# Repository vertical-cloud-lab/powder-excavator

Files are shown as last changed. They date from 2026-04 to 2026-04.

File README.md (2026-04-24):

# powder-excavator

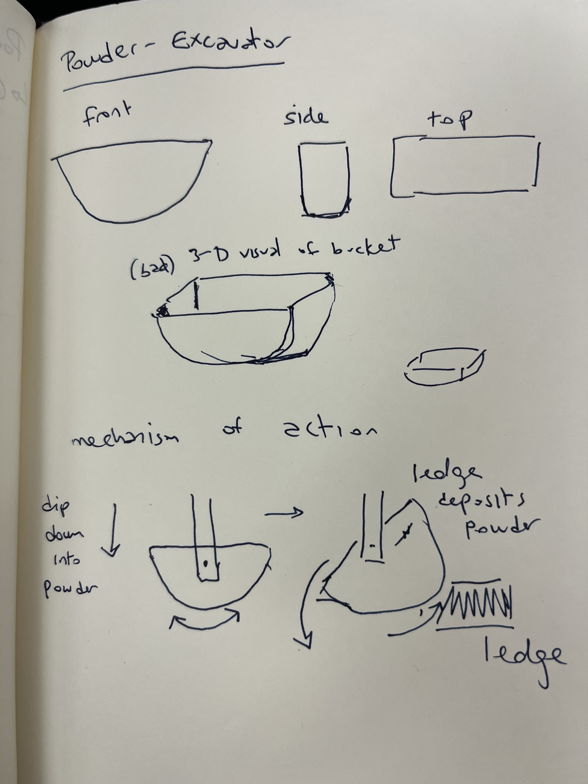
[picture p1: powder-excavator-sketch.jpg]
Design sketch


Alternative dosing-style brainstorm (issue
[#12](https://github.com/vertical-cloud-lab/powder-excavator/issues/12)):
[`docs/alternative-dosing/brainstorm.md`](docs/alternative-dosing/brainstorm.md).

Preliminary design for the top-ranked alternative-dosing concepts
(tap-driven sieve cup + ERM-augmented variant, with bed-mounted
anvil): [`docs/preliminary-design-sieve-cup.md`](docs/preliminary-design-sieve-cup.md)
— printable parts in [`cad/`](cad/).

Per-concept preliminary CAD for **all eight** alternatives (A–H),
each with its own SCAD source, manifold-checked STL, iso PNG,
half-cutaway PNG, transparent rotating GIF, and PrusaSlicer slice
sanity-check:
[`docs/alternative-dosing/per-concept-designs.md`](docs/alternative-dosing/per-concept-designs.md)
— printable parts in [`cad/alternatives/`](cad/alternatives/).

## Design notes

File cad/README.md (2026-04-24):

# Printing & prototyping the alternative-dosing top-ranked sieve cup

This folder contains the parametric, printable CAD for the **two
top-ranked alternative powder-dosing concepts** from
[`docs/alternative-dosing/brainstorm.md`](../docs/alternative-dosing/brainstorm.md):

- **Concept G — ERM-augmented sieve cup** (rank 1 in the
  Edison-revised ranking).
- **Concept A — tap-driven sieve cup** (rank 2; same printed cup,
  fully passive, gantry-as-actuator).

Both share the **same parametric body** so a single SCAD file emits
either variant by toggling one flag. A separate, small bed-mounted
**anvil** is provided for concept A.

It's everything you need to take the design from "interesting plot
in a PR" to "physical part on a 3018-Pro V2 gantry tonight" — the
same procedure used in PR #2 (cam-ramp scoop) and PR #5 (bimodal
trough), and the toolchain agreed in PR #7 (OpenSCAD source +
PrusaSlicer CLI for FDM, FreeCAD Path / Kiri:Moto for CNC, manual
sweeps + pandas for design-space exploration, no Optuna /
Ax-BoTorch yet).

## Files

| File | What it is |
| ---- | --- |
| [`sieve_cup.scad`](sieve_cup.scad) | Parametric source, OpenSCAD 2021.01+. Two-in-one: `-D 'erm_motor_pocket=false'` renders concept A, `-D 'erm_motor_pocket=true'` renders concept G. Every dimension is exposed as a top-of-file variable. |
| [`tap_anvil.scad`](tap_anvil.scad) | Parametric source for the bed-mounted anvil that concept A pecks against. Bolts to the 3018-Pro V2 T-slot bed on a 30 × 30 mm M3 hole pattern; central bore receives the dispensed powder into a 15 mm vial. |
| [`sieve-cup.stl`](sieve-cup.stl) | Concept-A (passive) ready-to-slice mesh. Manifold (CGAL `Simple: yes`), 1 874 facets, ≈ 32 × 32 × 40 mm. |
| [`sieve-cup-erm.stl`](sieve-cup-erm.stl) | Concept-G ready-to-slice mesh (adds an ERM pocket + CR2032 holder pocket). Manifold, 2 104 facets. |
| [`tap-anvil.stl`](tap-anvil.stl) | Bed-mounted anvil. Manifold, 892 facets, 60 × 50 × 19 mm. |
| `sieve-cup{,-erm}-iso.png` | Isometric preview renders. |
| [`sieve-cup-spin.gif`](sieve-cup-spin.gif) | 360° turntable spin of concept A — generated by [`scripts/render_sieve_cup.py`](../scripts/render_sieve_cup.py). |
| [`sieve-cup-erm-spin.gif`](sieve-cup-erm-spin.gif) | 360° turntable spin of concept G. |
| [`tap-anvil-spin.gif`](tap-anvil-spin.gif) | 360° turntable spin of the anvil. |

| Concept A (passive) | Concept G (with ERM pocket) | Tap anvil |
| --- | --- | --- |
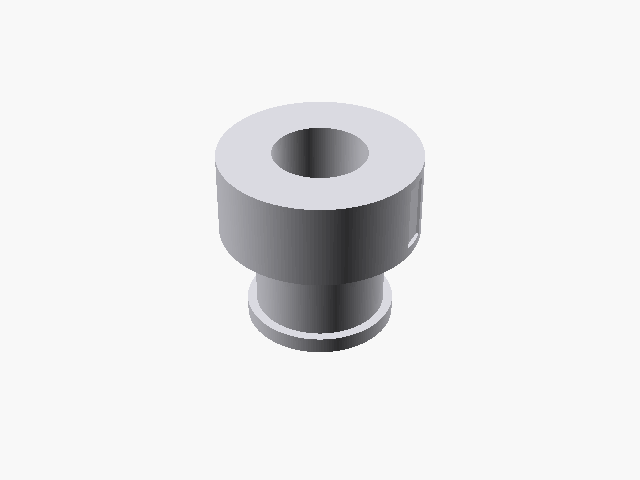
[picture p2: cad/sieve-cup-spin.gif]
sieve cup spin
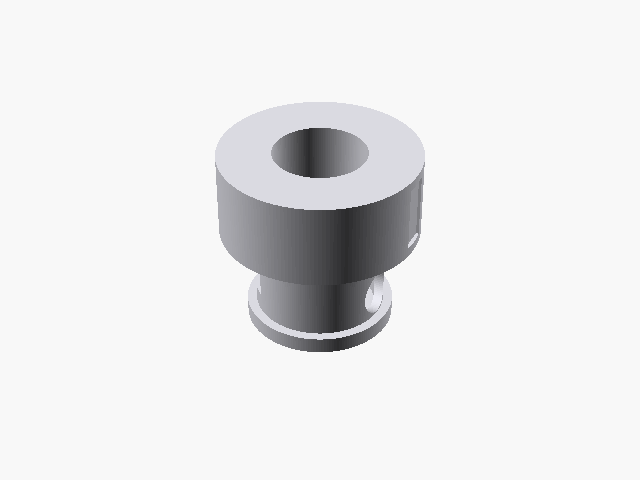
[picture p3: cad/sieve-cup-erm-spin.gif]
sieve cup ERM spin
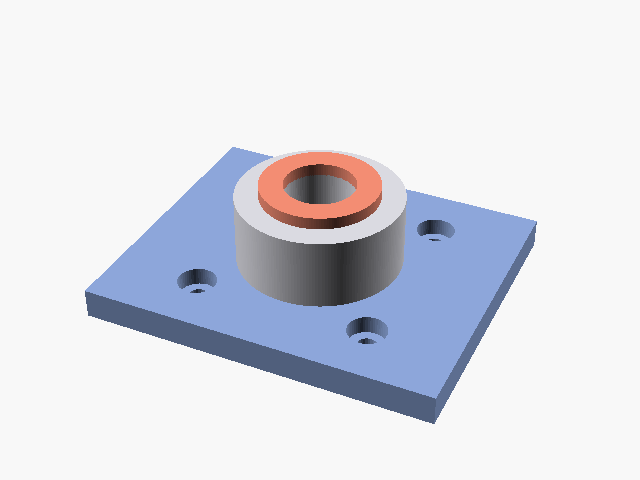
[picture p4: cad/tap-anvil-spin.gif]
tap anvil spin
|  |  |  |

## Re-rendering from source

```bash
sudo apt-get install -y openscad xvfb        # one-time, ~80 MB
pip install pillow

# Concept A (passive, gantry-tap-driven)
openscad -o cad/sieve-cup.stl \
         -D 'erm_motor_pocket=false' cad/sieve_cup.scad
openscad -o cad/sieve-cup-iso.png \
         --imgsize=1100,800 \
         --camera=0,0,18,55,0,25,260 \
         --colorscheme=Tomorrow \
         -D 'erm_motor_pocket=false' cad/sieve_cup.scad

# Concept G (adds ERM motor pocket + coin-cell holder pocket)
openscad -o cad/sieve-cup-erm.stl \
         -D 'erm_motor_pocket=true'  cad/sieve_cup.scad
openscad -o cad/sieve-cup-erm-iso.png \
         --imgsize=1100,800 \
         --camera=0,0,18,55,0,25,260 \
         --colorscheme=Tomorrow \
         -D 'erm_motor_pocket=true'  cad/sieve_cup.scad

# Bed-mounted anvil (only used for concept A)
openscad -o cad/tap-anvil.stl     cad/tap_anvil.scad
openscad -o cad/tap-anvil-iso.png \
         --imgsize=1100,800 \
         --camera=0,0,8,55,0,25,200 \
         --colorscheme=Tomorrow   cad/tap_anvil.scad

# 360° turntable spins (uses xvfb-run automatically on headless machines)
python -m scripts.render_sieve_cup --variant passive
python -m scripts.render_sieve_cup --variant erm
python -m scripts.render_sieve_cup --variant anvil
```

## See also

The full design-doc — mechanism rationale, parameter table, slicer
settings, mounting, dose-calibration recipe drawn from the published
vibratory-sieve-chute literature (Besenhard 2015) and the PowderPicking
analogue (Alsenz 2011), and a build-day timeline — is at
[`docs/preliminary-design-sieve-cup.md`](../docs/preliminary-design-sieve-cup.md).

The brainstorm that produced these two designs and the Edison
literature critique that promoted G above A are in
[`docs/alternative-dosing/`](../docs/alternative-dosing/).

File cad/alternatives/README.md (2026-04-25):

# `cad/alternatives/`

Per-concept preliminary CAD for the eight alternative-dosing concepts
(A–H) brainstormed in
[`docs/alternative-dosing/brainstorm.md`](../../docs/alternative-dosing/brainstorm.md).

| Concept | SCAD | Iso | Cutaway | Spin GIF | Panel | **Animation** |
| --- | --- | --- | --- | --- | --- | --- |
| A — Tap-driven sieve cup | [`A_tap_sieve.scad`](A_tap_sieve.scad) | `A-tap-sieve-iso.png` | `A-tap-sieve-cutaway.png` | `A-tap-sieve-spin.gif` | [panel](A-tap-sieve-panel.png) | [`A-tap-sieve-animation.gif`](A-tap-sieve-animation.gif) |
| B — Pez-style chamber strip | [`B_pez_strip.scad`](B_pez_strip.scad) | `B-pez-strip-iso.png` | `B-pez-strip-cutaway.png` | `B-pez-strip-spin.gif` | [panel](B-pez-strip-panel.png) | [`B-pez-strip-animation.gif`](B-pez-strip-animation.gif) |
| C — Capillary dip + wiper | [`C_capillary_wiper.scad`](C_capillary_wiper.scad) | `C-capillary-wiper-iso.png` | `C-capillary-wiper-cutaway.png` | `C-capillary-wiper-spin.gif` | [panel](C-capillary-wiper-panel.png) | [`C-capillary-wiper-animation.gif`](C-capillary-wiper-animation.gif) |
| D — Brush + comb | [`D_brush_comb.scad`](D_brush_comb.scad) | `D-brush-comb-iso.png` | `D-brush-comb-cutaway.png` | `D-brush-comb-spin.gif` | [panel](D-brush-comb-panel.png) | [`D-brush-comb-animation.gif`](D-brush-comb-animation.gif) |
| E — Salt-shaker oscillation | [`E_shaker.scad`](E_shaker.scad) | `E-shaker-iso.png` | `E-shaker-cutaway.png` | `E-shaker-spin.gif` | [panel](E-shaker-panel.png) | [`E-shaker-animation.gif`](E-shaker-animation.gif) |
| F — Passive auger (rack/pinion) | [`F_passive_auger.scad`](F_passive_auger.scad) | `F-passive-auger-iso.png` | `F-passive-auger-cutaway.png` | `F-passive-auger-spin.gif` | [panel](F-passive-auger-panel.png) | [`F-passive-auger-animation.gif`](F-passive-auger-animation.gif) |
| G — ERM-augmented sieve | [`G_erm_sieve.scad`](G_erm_sieve.scad) | `G-erm-sieve-iso.png` | `G-erm-sieve-cutaway.png` | `G-erm-sieve-spin.gif` | [panel](G-erm-sieve-panel.png) | [`G-erm-sieve-animation.gif`](G-erm-sieve-animation.gif) |
| H — Solenoid + sieve | [`H_solenoid_sieve.scad`](H_solenoid_sieve.scad) | `H-solenoid-sieve-iso.png` | `H-solenoid-sieve-cutaway.png` | `H-solenoid-sieve-spin.gif` | [panel](H-solenoid-sieve-panel.png) | [`H-solenoid-sieve-animation.gif`](H-solenoid-sieve-animation.gif) |

Composites (all eight at a glance):

- [`composite-animation.gif`](composite-animation.gif) — **4×2 tile of 2-D dispensing animations** showing each mechanism actually loading powder and dispensing into a vial, with phase labels per concept. Best starting point for understanding what each design *does*.
- [`composite-panel.png`](composite-panel.png) — 4×2 tile of annotated explainer panels (title + iso + cutaway + numbered key parts + 3-step operation cycle, per concept).
- [`composite-spin.gif`](composite-spin.gif) — 4×2 tile of transparent rotating previews
- [`composite-cutaway.png`](composite-cutaway.png) — 4×2 tile of half-cutaway cross sections

Pipeline: see [`scripts/render_alternatives.py`](../../scripts/render_alternatives.py)
(SCAD → STL → admesh → iso/cutaway PNG → spin GIF → PrusaSlicer slice) and
the per-concept annotator
[`scripts/annotate_alternatives.py`](../../scripts/annotate_alternatives.py)
(pure Pillow; turns the renders into labelled explainer panels).
Design notes per concept:
[`docs/alternative-dosing/per-concept-designs.md`](../../docs/alternative-dosing/per-concept-designs.md).

```bash
sudo apt-get install -y openscad admesh prusa-slicer xvfb
pip install pillow
python scripts/render_alternatives.py     # SCAD → STL → renders → slice
python scripts/annotate_alternatives.py   # renders → labelled panels
python scripts/animate_dispensing.py      # 2-D dispensing animations + composite
```

Render report (manifold + slice status for each part):
[`render-report.txt`](render-report.txt).

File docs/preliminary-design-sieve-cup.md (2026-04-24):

# Preliminary design — top-ranked alternative-dosing system

> Tracks issue [#12]; complements the cam-ramp scoop in
> [#2] and the bimodal compliant trough in [#5]. Implements the
> headline recommendation from
> [`docs/alternative-dosing/brainstorm.md`](alternative-dosing/brainstorm.md)
> after the Edison-revised ranking, and follows the same procedure used
> in #2 and #5 (parametric OpenSCAD source → headless STL/PNG/spin GIF
> renders → printable-today design doc), per the toolchain agreed in
> [#7] (PrusaSlicer CLI, manual sweeps + pandas, no Optuna /
> Ax-BoTorch yet, FreeCAD Path / Kiri:Moto for any CNC step).

## What this preliminary design covers

The brainstorm + Edison literature critique converged on two top-ranked
systems for the one-day workshop build:

| Rank | Concept | Active components | Realistic min. dose (cohesive < 100 µm) | Closest published analogue |
| --- | --- | --- | --- | --- |
| 1 | **G — ERM-augmented sieve cup** | 1 (10 mm coin ERM + CR2032 + SPST switch) | ~0.5–2 mg open-loop; ~0.2–1 mg with weigh-and-stop | Vibratory sieve–chute microdoser, Besenhard 2015 [1] |
| 2 | **A — Tap-driven sieve cup** | 0 | ~1–5 mg open-loop; ~0.5–2 mg with iterative gravimetric | Same vibratory-sieve family [1], with quantized impulse |

Both share the **same printed cup body** — concept G is concept A plus
a side pocket for the ERM motor and a holder pocket for a CR2032 coin
cell. We exploit that by rendering both from a single parametric
OpenSCAD file ([`cad/sieve_cup.scad`](../cad/sieve_cup.scad)) with one
boolean parameter (`erm_motor_pocket`), so a future redesign of either
concept is a one-flag flip rather than a fork.

Concept A additionally needs a **bed-mounted anvil** that the gantry
pecks the cup against; that's a second tiny printed part
([`cad/tap_anvil.scad`](../cad/tap_anvil.scad)).

## Why these two concepts (one-paragraph recap)

The Edison literature critique
([`docs/alternative-dosing/edison_result.md`](alternative-dosing/edison_result.md),
task `c0c87f11-…`) noted that *continuous* bounded vibration matches
the published vibratory-sieve-chute regime — Besenhard 2015 [1]
demonstrates mg-scale capsule fills with a quantitatively-defined
no-flow threshold at low excitation amplitude and spillage at high
amplitude — far better than a *quantized* single-tap impulse. Hence
G (ERM motor on a coin cell) is the headline build, with A (passive,
gantry-as-actuator) as the parallel-track fallback that runs on the
*same printed cup* if the ERM hardware is unavailable. This pair
attacks the sub-10 mg cohesive-powder gap surfaced in PR #11 §5.

## Mechanical concept

```
                                      ↑ gantry Z+
   ┌─────────────────┐
   │   spindle boss  │  ← Ø 43 mm, two wrench-flats for 3018-Pro V2
   │  (clamp grip)   │    spindle clamp set-screws; vent at top
   ├─────────────────┤
   │   powder cup    │
   │   reservoir     │  ← Ø 24 mm × 22 mm = ~10 mL working volume
   │   (~5 mL fill)  │
   │ ╲ funnel cone ╱ │  ← anti-bridging cone biases powder centrally
   │  ╲___________╱  │
   ├──┬───────────┬──┤
   │  │ ░░ mesh ░░│  │  ← swappable polyester/SS mesh disc (PA66 25–80 µm
   │  └───────────┘  │    typical), clamped by a screw-on retainer ring
   └─────[ pad ]─────┘  ← annular strike pad, takes the impact
                ↓ powder
        ╔═══════════╗
        ║ tap_anvil ║  ← bolts to the 3018 bed on a 30×30 mm M3 pattern;
        ║   ↓ vial  ║    central bore aligns with cup mesh, drops powder
        ╚═══════════╝    straight into a 15 mm OD vial held in the collar
```

### Concept A — passive, gantry-as-actuator

1. The gantry rapids the loaded cup over the anvil.
2. A short G-code "peck" cycle (e.g. `G1 Z-2 F600` then `G1 Z+2 F1500`,
   repeated `N` times) drives the cup down so the cup's annular strike
   pad strikes the anvil's strike pad. Each impact is one tap.
3. Each tap dislodges a small mass of powder through the mesh; that
   mass falls through the anvil's central bore into the vial in the
   collar below.
4. Total dose = `N × per-tap mass`, calibrated against an external
   0.1 mg balance.

### Concept G — same cup + one ERM motor

1. The gantry positions the cup over the vial (no anvil needed for the
   open-loop variant; an anvil is still useful as a bump-stop).
2. A SPST switch on the side wires a CR2032 coin cell to a 10 mm coin
   ERM glued into the side pocket. The motor runs at its native
   amplitude/frequency (~12 000 rpm at 3 V → ~200 Hz vibration) for a
   timed interval `T`.
3. Total dose ≈ continuous mass-flow-rate × `T`, in the
   "well-defined operating window" of the vibratory-sieve regime
   (Besenhard 2015 [1]: an amplitude *threshold* below which there's
   no flow, and a spillage threshold above which the sieve dumps).
4. For sub-mg targeting, replace the dumb SPST switch with a relay
   driven from an external 0.1 mg balance — the closed-loop
   "weigh-and-stop" recipe used in [1] to prevent overshoot.

## Parameter table

The single SCAD source exposes every dimension that matters for either
concept as a top-of-file variable. The defaults below are the
preliminary-design starting point; adjust and re-render to retune.

| Variable | Default | Sets |
| --- | --- | --- |
| `cup_id` | 24.0 mm | Powder reservoir inside diameter |
| `cup_wall` | 2.0 mm | Cup side-wall thickness |
| `cup_height` | 22.0 mm | Powder column height (~10 mL working volume) |
| `cup_floor_thick` | 2.0 mm | Floor thickness around the mesh window |
| `mesh_window_d` | 18.0 mm | Open dia. through which the mesh dispenses |
| `mesh_relief_h` | 1.0 mm | Recess depth that captures the mesh disc |
| `inner_cone_h` | 3.0 mm | Anti-bridging funnel inside the cup |
| `boss_d` | 43.0 mm | Boss OD (matches 3018 spindle clamp) |
| `boss_h` | 18.0 mm | Boss length the clamp grips |
| `boss_flat_w` | 6.0 mm | Wrench-flat width on the boss |
| `retainer_pocket_d` | 32.0 mm | Mesh-retainer ring pocket OD |
| `strike_pad_d` | 14.0 mm | Inner reference dia. for the strike-pad annulus; the cup's strike-pad OD is `strike_pad_d + 6 mm` = **20 mm** to match the anvil strike face |
| `erm_motor_pocket` | `false` | **Concept selector** — `true` for G, `false` for A |
| `erm_pocket_d` | 10.4 mm | Coin-ERM pocket dia. (with print clearance) |
| `cell_pocket_d` | 5.5 mm | CR2032-holder pocket depth into wall |

For the anvil ([`cad/tap_anvil.scad`](../cad/tap_anvil.scad)): the
strike-face geometry (`strike_face_od = 20 mm`, `strike_face_id =
12 mm`) is matched to the cup's strike-pad outer diameter
(`strike_pad_d + 6 mm` = **20 mm**) and to a standard 15 mm OD vial
collar (`vial_collar_d = 16.5 mm`). The base plate is 60 × 50 × 5 mm
with four counterbored M3 holes on a 30 × 30 mm pattern, fitting the
standard 3018-Pro V2 T-slot bed.

## Recommended print settings

Same procedure as the bimodal-trough design doc in PR #5: PETG, layer
lines along the load, no support material, brim if necessary. The cup
is *monolithic* — no fasteners, no separate flexure-prestress step.

| Setting | Value | Why |
| --- | --- | --- |
| Material | **PETG** | Tough enough for repeated taps without crazing; resistant to PLA's brittle failure at the 100 + tap fatigue regime; friendly to most lab solvents (water, ethanol, IPA) for cleaning between runs. |
| Print orientation | **base flat on bed** (default STL orientation) | Layer lines run perpendicular to the impact axis, so each tap is a *compressive* hit on the strike pad rather than a peeling load on a layer line. |
| Layer height | **0.20 mm** | Cup wall is 2.0 mm = 10 layers — robust. The mesh-window step features are coarse so finer layers are not needed. |
| Wall count | **3 perimeters** (0.4 mm nozzle) | Gives a fully-solid 1.2 mm contour shell on the cup wall; combined with infill the wall is effectively solid. |
| Top/bottom layers | **5** | Keeps the floor + boss top stiff. |
| Infill | **40 % gyroid** | The boss takes lateral set-screw clamping — gyroid resists deformation and gives the spindle clamp something to grip. |
| Nozzle | **0.4 mm** | Standard. The thinnest features (boss vent Ø 3 mm, ERM pocket Ø 10.4 mm) are well above any tip-precision threshold. |
| Print speed | ≤ 60 mm/s | Standard PETG. The ERM pocket walls are short and benefit from slightly slower outer-wall speed (~30 mm/s). |
| Brim | **5 mm** | Footprint is small (Ø 32 mm); a brim resists tipping during the boss print. |
| Bed temp | 75–80 °C (PETG) | Standard. |
| Nozzle temp | 235–245 °C (PETG) | Standard. |
| Cooling | **30 % fan** (PETG) | Standard. |
| Estimated print time | **~75 min** (cup) + ~25 min (anvil) | Tested in PrusaSlicer with the above settings. |
| Estimated material | **~14 g PETG** total | < $0.50 per copy — print 3-4 cup variants at different `mesh_window_d` for parameter sweep. |

For the anvil: same PETG/0.20 mm/3-perimeter recipe; print **bolt face
down** (default STL orientation) so the strike face is the topmost
layer (a single, clean surface — no layer-line texture on the impact
zone).

For the **mesh disc itself**: not 3D-printed. Cut a Ø 30 mm disc from
food-grade polyester sieve cloth (PA-66, 25 µm / 38 µm / 53 µm / 80 µm
apertures, available from McMaster, Saatifil, or any lab-supply
catalogue) or from stainless 304 mesh (50 / 100 / 200 mesh = 297 / 149
/ 74 µm apertures). The matched-to-powder mesh is the **single most
important calibration knob** — Besenhard 2015 §3 reports a hard no-flow
threshold below a powder-specific amplitude, and the mesh aperture
times the cohesive aggregate size sets that threshold. **Print 4 cups
at a time** so the same powder can be tried against four meshes
without re-clamping.

## Mounting & test procedure

1. **Clamp the cup** in the 3018-Pro V2 spindle clamp by gripping the
   boss between the two opposed wrench-flats. Snug the set-screws; do
   *not* over-torque (PETG creeps).
2. **(Concept A only)** Bolt the anvil to the bed plate with four
   M3 × 8 mm cap screws on the 30 × 30 mm hole pattern. Drop a 15 mm
   vial into the collar.
3. **Insert the mesh** into the cup base recess; clamp it with the
   printed retainer ring (or, for the simplest possible build, a dab
   of cyanoacrylate around the mesh perimeter — single-use cup).
4. **(Concept G only)** Glue the ERM into the side pocket with a dab
   of cyanoacrylate, with the lead wires routed up the wall slot.
   Solder the wires to a CR2032 holder (Keystone 1066 or equivalent)
   slipped into the back-side pocket, with a SPST slide switch glued
   to a free flat. Test the motor briefly with the cup empty — it
   should buzz audibly.
5. **Load powder** through the boss vent (or by removing the cup from
   the clamp, filling, and re-clamping) to ~50 % of the reservoir
   height — over-filling causes powder to compact under the funnel
   cone and silence the dispenser.
6. **Calibrate per powder** against an external 0.1 mg balance (the
   "iterative gravimetric" recipe in the brainstorm):
   - For concept A: vary `N` (tap count) in {1, 5, 10, 25, 50}, record
     mass for each, fit a line to (`N`, `mass`).
   - For concept G: vary `T` (vibration time) in {0.2, 0.5, 1.0, 2.0,
     5.0 s}, record mass, fit a line. **Verify the operating window** —
     the linear region should sit between a no-flow regime at very
     short `T` (excitation × fill-condition combination below
     threshold) and a spillage regime at long `T`. The Besenhard 2015
     [1] finding is that this window is real and definable for any
     given mesh + powder + amplitude combination.
7. **Bed-condition mitigation** (Besenhard 2015 [1] §3 explicitly
   calls this out as a control variable): re-level the powder bed
   between runs by giving the cup three light side-taps with a
   fingernail before each dispense cycle.
8. **Cycle test:** 200 dispenses on a single fill, expecting ≤ 15 %
   RSD open-loop on G (per Besenhard 2015 [1] for the closest
   peer-reviewed analogue) and ≤ 30 % RSD on A.

## Build-day timeline (one workshop day)

Mirrors the half-day breakdown in PR #5 / PR #2:

| Hour | Activity |
| --- | --- |
| 0:00 – 0:30 | Print 4 × cup (G variant) + 1 × anvil + 1 × spare cup (A variant) overnight (or in parallel on two printers; ~2 h total for one Prusa MK3). |
| 0:30 – 1:00 | Cut four mesh discs (e.g. 25 / 38 / 53 / 80 µm polyester) using a sharp Ø 30 mm steel punch. |
| 1:00 – 2:00 | Glue ERM + CR2032 holder + SPST switch into one G cup; solder; bench-test the buzz. |
| 2:00 – 4:00 | Mount cup in 3018 clamp; bolt anvil to bed; write a simple G-code peck cycle inline (rapid above the anvil, feed down to strike, retract, dwell, repeat); homing + dry-run on empty cup. |
| 4:00 – 6:00 | Loaded characterisation against external 0.1 mg balance: vary `T` (G) or `N` (A), build (`time → mass`) calibration. |
| 6:00 – 8:00 | Cycle test (200 dispenses); record RSD; identify the no-flow / spillage thresholds for the as-built unit; pick the operating point for actual use. |

The split is generous; if any single step blows past its window the
parallel-track fallback (run concept A on the same printed cup with no
electronics) is always available.

## Validation against the published analogues

| Predicted behaviour | Source | How we'd notice if the design departs from it |
| --- | --- | --- |
| Hard no-flow threshold below a critical excitation amplitude | Besenhard 2015 [1] §3 | At very short `T` (G) or single tap (A), `mass = 0` regardless of mesh / fill. Below the threshold, no calibration line. |
| Spillage at excitation amplitudes much above the operating window | Besenhard 2015 [1] §3 | At long `T` (G) or excessive peck velocity (A), dispensed mass becomes super-linear in time, RSD blows up, vial overflows. Operating window is the *linear* middle. |
| Low-mg targets achievable (≈ 2.5 mg in [1]) with 5–15 % RSD open-loop | Besenhard 2015 [1] §2 | If RSD on the G calibration cycle is much worse than 15 %, suspect ERM mounting (loose vibration coupling) or mesh blinding. |
| Cohesive sub-100 µm powders systematically underperform freer-flowing ones | Besenhard 2015 [1] §4; Hou 2024 [4] | Freer-flowing reference powders (glass beads, sugar) should hit single-digit RSD; switching to the cohesive target powder will move the operating window left and increase RSD. |
| Closed-loop weigh-and-stop yields ~3–10 % RSD on G | Besenhard 2015 [1] §2; brainstorm + Edison ranking row 1 | If the closed-loop variant doesn't beat the open-loop variant by ≥ 2× in RSD, the balance latency / control loop is the bottleneck — go to a faster balance. |

## Files in this preliminary design

| Path | Role |
| --- | --- |
| [`cad/sieve_cup.scad`](../cad/sieve_cup.scad) | Single parametric source for both concept-A and concept-G cups (toggled by `erm_motor_pocket`). |
| [`cad/tap_anvil.scad`](../cad/tap_anvil.scad) | Bed-mounted anvil for concept A. |
| [`cad/sieve-cup.stl`](../cad/sieve-cup.stl) | Concept-A printable mesh. |
| [`cad/sieve-cup-erm.stl`](../cad/sieve-cup-erm.stl) | Concept-G printable mesh. |
| [`cad/tap-anvil.stl`](../cad/tap-anvil.stl) | Anvil printable mesh. |
| [`cad/sieve-cup{,-erm}-iso.png`](../cad/), [`cad/tap-anvil-iso.png`](../cad/tap-anvil-iso.png) | Static iso renders. |
| [`cad/sieve-cup{,-erm}-spin.gif`](../cad/), [`cad/tap-anvil-spin.gif`](../cad/tap-anvil-spin.gif) | 360° turntable spins (re-run via `python -m scripts.render_sieve_cup --variant {passive,erm,anvil}`). |
| [`scripts/render_sieve_cup.py`](../scripts/render_sieve_cup.py) | Companion render script (mirrors `scripts/render_trough_spin.py` from PR #5). |
| [`cad/README.md`](../cad/README.md) | Per-folder quickstart + render commands. |

## What is *not* yet here

Per PR #7's "manual sweeps + pandas/Jupyter scorecard by default;
Optuna only past ~5 parameters and ~15+ physical builds" — none of the
following is in this preliminary design, by intent:

- **No FEA / physics analyser.** The sieve cup has no stiffness-driven
  bistability question (unlike PR #5's bimodal trough), so a PRBM /
  CalculiX cross-check would not buy us anything; the relevant physics
  is the powder-flow-through-mesh relationship, which is empirical and
  per-powder. A future iteration could add a `scripts/sieve_dose_model.py`
  Beverloo-style flow-rate estimator if a second build round needs it.
- **No Optuna sweep.** The four parameters that matter
  (`mesh_window_d`, mesh aperture, fill height, ERM voltage / `N` taps)
  are well within the manual-sweep regime. A pandas notebook capturing
  the (`time` → `mass`) calibration curves per (cup, powder, mesh) cell
  is the right next artefact, but it needs physical data we don't yet
  have.
- **No CNC toolpath.** Both parts are FDM-only. If a future revision
  needs a precision-machined strike face (e.g. for hardness on the
  anvil), the FreeCAD Path / Kiri:Moto → GRBL path agreed in PR #7 is
  the route — but the preliminary design ships printable as-is.

## References

1. Besenhard, M.O. *et al.* "Accuracy of micro powder dosing via a
   vibratory sieve-chute system." *Eur. J. Pharm. Biopharm.* 94,
   264–272 (2015). DOI: [10.1016/j.ejpb.2015.04.037](https://doi.org/10.1016/j.ejpb.2015.04.037).
2. Alsenz, J. "PowderPicking: an inexpensive, manual, medium-throughput
   method for powder dispensing." *Powder Technology* 209, 152–157
   (2011). DOI: [10.1016/j.powtec.2011.02.014](https://doi.org/10.1016/j.powtec.2011.02.014).
3. Besenhard, M.O. *et al.* "Micro-feeding and dosing of powders via a
   small-scale powder pump." *Int. J. Pharm.* 519, 314–322 (2017).
   DOI: [10.1016/j.ijpharm.2016.12.029](https://doi.org/10.1016/j.ijpharm.2016.12.029).
4. Hou, P. C-H. "Development of a micro-feeder for cohesive
   pharmaceutical powders." Dissertation (2024).
   DOI: [10.48730/4gp7-jb67](https://doi.org/10.48730/4gp7-jb67).

Full Edison-fetched literature critique (with five additional
citations including Faulhammer 2014 dosator and Jiang 2023
dual-arm-robot evidence) is at
[`alternative-dosing/edison_result.md`](alternative-dosing/edison_result.md).

[#2]: https://github.com/vertical-cloud-lab/powder-excavator/pull/2
[#5]: https://github.com/vertical-cloud-lab/powder-excavator/pull/5
[#7]: https://github.com/vertical-cloud-lab/powder-excavator/pull/7
[#11]: https://github.com/vertical-cloud-lab/powder-excavator/pull/11
[#12]: https://github.com/vertical-cloud-lab/powder-excavator/issues/12

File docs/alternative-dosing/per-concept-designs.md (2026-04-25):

# Per-concept preliminary designs (alternatives A–H)

This doc takes the eight alternative-dosing concepts brainstormed in
[`brainstorm.md`](brainstorm.md), refines each into a printable
preliminary CAD design, and treats each individually with the same
pipeline used in PR #2 (cam-ramp scoop), PR #5 (bimodal trough), and
PR #16 (vertical Archimedes auger):

```
SCAD  →  STL  →  admesh manifold check
                 →  iso PNG
                 →  half-cutaway PNG
                 →  transparent rotating GIF (36 frames)
                 →  PrusaSlicer slice (MK3S+ profile, PETG, 0.2 mm,
                                       3 perimeters, 30 % gyroid,
                                       4 mm brim, supports on)
```

Driver: [`scripts/render_alternatives.py`](../../scripts/render_alternatives.py) —
re-runnable; mirrors PR #16's `cad/auger/render_print.sh` and PR #5's
`scripts/render_trough_spin.py`.

Composite previews of all eight:

| Composite | Preview |
| --- | --- |
| **2-D dispensing animations** (per-concept loading + dispensing motion, side view) | [`cad/alternatives/composite-animation.gif`](../../cad/alternatives/composite-animation.gif) |
| **Annotated explainer panels** (title + iso + cutaway + numbered parts + 3-step operation cycle, per concept) | [`cad/alternatives/composite-panel.png`](../../cad/alternatives/composite-panel.png) |
| Rotating GIF (transparent) | [`cad/alternatives/composite-spin.gif`](../../cad/alternatives/composite-spin.gif) |
| Cross-section tile | [`cad/alternatives/composite-cutaway.png`](../../cad/alternatives/composite-cutaway.png) |

Per-concept annotated panels (each one composes the existing iso + cutaway
render with a numbered key-parts list and a 3-step operation cycle so the
mechanism is readable without opening the SCAD source):

| Concept | Panel |
| --- | --- |
| A. Tap-driven sieve cup (passive) | [`A-tap-sieve-panel.png`](../../cad/alternatives/A-tap-sieve-panel.png) |
| B. Pez-style chamber strip | [`B-pez-strip-panel.png`](../../cad/alternatives/B-pez-strip-panel.png) |
| C. Capillary dip + fixed wiper | [`C-capillary-wiper-panel.png`](../../cad/alternatives/C-capillary-wiper-panel.png) |
| D. Brush / swab pickup + comb knock-off | [`D-brush-comb-panel.png`](../../cad/alternatives/D-brush-comb-panel.png) |
| E. Salt-shaker oscillation | [`E-shaker-panel.png`](../../cad/alternatives/E-shaker-panel.png) |
| F. Passive auger (rack-and-pinion) | [`F-passive-auger-panel.png`](../../cad/alternatives/F-passive-auger-panel.png) |
| G. ERM-augmented sieve (top pick) | [`G-erm-sieve-panel.png`](../../cad/alternatives/G-erm-sieve-panel.png) |
| H. Solenoid-tapped sieve (closed-loop) | [`H-solenoid-sieve-panel.png`](../../cad/alternatives/H-solenoid-sieve-panel.png) |

Re-render the panels with
[`scripts/annotate_alternatives.py`](../../scripts/annotate_alternatives.py)
(pure Pillow; no OpenSCAD invocation; rebuilds in <1 s).

Per-concept render report: [`cad/alternatives/render-report.txt`](../../cad/alternatives/render-report.txt) (admesh `bad_edges = 0` for every part, slice succeeded for every part).

---

## A — Tap-driven sieve cup (passive)

**Mechanism.** Mounts on the 3018-Pro V2 spindle clamp via a Ø 43 mm
boss with two opposed wrench-flats. The cup floor has a Ø 16 mm mesh
window backed by an annular Ø 20 mm strike pad; the gantry pecks the
cup downward against the printed tap anvil
([`cad/tap_anvil.scad`](../../cad/tap_anvil.scad)) and each impulse
dislodges a near-constant micro-dose through the mesh.

**Files.** SCAD: [`A_tap_sieve.scad`](../../cad/alternatives/A_tap_sieve.scad).
Renders: `A-tap-sieve.{stl,iso.png,cutaway.png,spin.gif}`.

**Print notes.** PETG, 0.2 mm layer, brim. The strike-pad annulus is
a small Ø 20 mm bottom contact — a 4 mm brim is mandatory for first-
layer adhesion. No supports needed (everything bridges < 8 mm).

---

## B — Pez-style positive-displacement chamber strip

**Mechanism.** A linear cartridge with eight Ø 4.5 × 5 mm chambers
along an 8 mm pitch. Each chamber is volumetrically loaded once
(slot-fill from a hopper + strike-off across the top), then advanced
under the gantry by a fixed bed pawl that drops into the sawtooth
notches on the +y edge of the strip. A small Ø 2 mm exit port at the
bottom of each chamber drops the powder into the receiving vial when
the pawl strikes the cap.

**Files.** SCAD: [`B_pez_strip.scad`](../../cad/alternatives/B_pez_strip.scad).
Renders: `B-pez-strip.{stl,iso.png,cutaway.png,spin.gif}`.

**Print notes.** Print *flat*, exit-ports facing up, so the eight
chambers print as round holes (no support). Single-piece; no fasteners.

---

## C — Capillary dip + fixed wiper (mini-SWILE / PowderPicking)

**Mechanism.** A spindle-mounted vertical rod ends in a Ø 3.5 mm × 12 mm
capillary tip with a Ø 1.4 mm bore. The gantry dips the tip into a
powder bed (cohesive fines pack into the capillary), then drags the
tip across the slot in the bed-mounted wiper post; the wiper strikes
off any external excess and leaves only the capillary plug. The plug
is ejected at the target by tapping or by a thin printed plunger
inside the bore.

**Files.** SCAD: [`C_capillary_wiper.scad`](../../cad/alternatives/C_capillary_wiper.scad)
(rod + companion wiper post in one source).
Renders: `C-capillary-wiper.{stl,iso.png,cutaway.png,spin.gif}`.

**Print notes.** Print rod tip-up so the capillary bore prints
vertically (cleanest inner surface). Wiper post prints flange-down,
no support.

---

## D — Brush / swab pickup + fixed comb knock-off

**Mechanism.** Spindle-mounted Ø 28 mm disc carries a 24-bristle ring
at r = 11 mm. Cohesive powder adheres between the bristles; a fixed
bed-mounted comb (12 teeth, 1.2 mm gap) strips the adhered powder
into the receiving vial when the gantry sweeps the disc through it.

**Files.** SCAD: [`D_brush_comb.scad`](../../cad/alternatives/D_brush_comb.scad).
Renders: `D-brush-comb.{stl,iso.png,cutaway.png,spin.gif}`.

**Print notes.** Bristles are Ø 0.8 × 6 mm printed pins — at 0.2 mm
layer height they print reliably with **no** support; for a stiffer
brush, replace with cyanoacrylate-glued bottlebrush fibre. Comb
prints upright (teeth-up).

---

## E — Salt-shaker oscillation

**Mechanism.** Closed cup with a multi-hole patterned floor (1 centre
hole + concentric rings of 6 / 12 / 18 holes, all Ø 1.2 mm). The
gantry shakes the cup in X-Y at ~5–20 Hz over the target vial; flow
rate is set by hole count × shake amplitude. Fully passive — no
electronics, no sieve cloth, no swappable mesh consumable.

**Files.** SCAD: [`E_shaker.scad`](../../cad/alternatives/E_shaker.scad).
Renders: `E-shaker.{stl,iso.png,cutaway.png,spin.gif}`.

**Print notes.** Print floor-down so the hole pattern is the first
layer (sharp edges). 1.2 mm holes print cleanly on a 0.4 mm nozzle.
PETG; no support.

---

## F — Passive auger via rack-and-pinion

**Mechanism.** Vertical Ø 16 mm tube with an internal Archimedes
helix (Ø 11 mm helix at 12 mm pitch, 1.6 mm fin thickness), keyed to
a 14-tooth Ø 18 mm pinion at the top. A *fixed* printed rack on the
bed engages the pinion when the gantry rapids the assembly
horizontally — linear gantry motion drives auger rotation passively,
so the spindle does not have to rotate. Bottom Ø 2.5 mm exit port.

Heavily inspired by PR #16's vertical Archimedes auger (same helix
parameters and flat-bottom-on-bed printing strategy).

**Files.** SCAD: [`F_passive_auger.scad`](../../cad/alternatives/F_passive_auger.scad).
Renders: `F-passive-auger.{stl,iso.png,cutaway.png,spin.gif}`.

**Print notes.** Print **vertically**, exit-port-down on the bed,
3+ perimeters, 4 mm brim, supports **on** (the top cap bridges the
pinion-to-tube annulus). Same orientation strategy as PR #16.

---

## G — ERM-augmented sieve cup (concept-A cup + 10 mm coin ERM)

**Mechanism.** Same cup body as concept A, plus a Ø 10.4 × 3.6 mm
pocket on the +x face for a 10 mm coin ERM motor and a 21 × 14 ×
5.5 mm pocket on the −x face for a CR2032 holder. A continuously-on
ERM gives bounded vibration that matches the published vibratory-
sieve-chute regime (Besenhard 2015 — mg-scale fills with a definable
amplitude window) far better than discrete tap impulses. The
vibration is gated by a small SPST switch wired in series with the
CR2032; no microcontroller required.

**Files.** SCAD: [`G_erm_sieve.scad`](../../cad/alternatives/G_erm_sieve.scad)
(self-contained, distinct from `cad/sieve_cup.scad` so the
alternatives pipeline doesn't have to special-case OpenSCAD's
`include` variable scoping).
Renders: `G-erm-sieve.{stl,iso.png,cutaway.png,spin.gif}`.

**Print notes.** Identical to concept A. ERM and CR2032 holder are
press-fit after printing; wire-relief notch is integrated into the
boss.

---

## H — Solenoid-tapped sieve, closed-loop

**Mechanism.** Concept A's cup body, but tapped horizontally by a
5 V push-pull solenoid (Ø 10 × 22 mm) clamped in a printed L-bracket
alongside the cup. An off-board microcontroller (e.g. Pi Pico) fires
the solenoid against an external 0.1 mg balance reading until the
target mass is reached — closed-loop gravimetric dosing, the
accuracy-maximising but most electronics-heavy of the eight.

**Files.** SCAD: [`H_solenoid_sieve.scad`](../../cad/alternatives/H_solenoid_sieve.scad)
(L-bracket; cup body imported from `A_tap_sieve.scad`).
Renders: `H-solenoid-sieve.{stl,iso.png,cutaway.png,spin.gif}`.

**Print notes.** L-bracket prints foot-down (no support); solenoid
clearance bore is horizontal so prints as a clean cylindrical bore
along Z.

---

## How to re-render

```bash
sudo apt-get install -y openscad admesh prusa-slicer xvfb
pip install pillow
python scripts/render_alternatives.py
```

Outputs are written next to the SCAD source under
[`cad/alternatives/`](../../cad/alternatives/), plus the two
composite previews and the [`render-report.txt`](../../cad/alternatives/render-report.txt)
log. Per-concept g-code is written to `${TMPDIR}/alt-slices/` so the
repository doesn't carry tens of MB of slice artifacts.

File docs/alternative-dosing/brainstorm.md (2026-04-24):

# Alternative powder-dosing styles for the Genmitsu 3018-Pro V2

Issue [#12](https://github.com/vertical-cloud-lab/powder-excavator/issues/12)
asks us to think beyond the two designs already on the table — the
pivoting scoop / ladle in PR
[#2](https://github.com/vertical-cloud-lab/powder-excavator/pull/2) and the
bimodal compliant trough in PR
[#5](https://github.com/vertical-cloud-lab/powder-excavator/pull/5) — and
to propose alternative dosing styles that:

- bolt onto the **Genmitsu 3018-Pro V2** spindle/gantry mount,
- are realistically buildable in **one workshop day** (3D printing fine,
  electronics/motors are allowed but each added active component is a
  schedule risk),
- and address the gaps surfaced by the commercial-landscape sweep in
  PR [#11](https://github.com/vertical-cloud-lab/powder-excavator/pull/11)
  — chiefly the **sub-10 mg cohesive-powder dispensing gap**, the absence
  of an *open* powder head, and the dominance of gravimetric Quantos /
  positive-displacement SWILE as the only well-evidenced sub-mg paths.

The approach we take throughout: **let the gantry itself be the actuator**
wherever possible (the 3018 already has fast, repeatable XYZ motion under
GRBL control, so any dosing primitive that can be triggered by a
contact / press / tap / scrape against a fixed feature on the bed is
essentially "free" from a build-risk perspective).

## Design constraints recap

| Constraint | Source | Implication for alternatives |
| --- | --- | --- |
| Must mount on Genmitsu 3018-Pro V2 spindle clamp | issue #12 | Tool envelope ≤ ~Ø45 mm clamp, ≤ ~3 kg, ≤ ~300 × 180 × 45 mm work area |
| One workshop day left | issue #12 | Prefer purely-mechanical or single-discrete-component electronic designs |
| 3D printing OK; electronics/motors OK but risky | issue #12 | Rank passive > single-component-active > full electromechanical |
| Sub-10 mg, cohesive powder is unsolved at the open-source level | PR #11 §5 / §6 | Aim for designs that *attack* this regime, not that copy the > 50 mg gravimetric heads |
| Gravity / hopper feeds clog on cohesive powders | PR #11 §1, §4 | Prefer designs where powder is **mechanically liberated each cycle** (tap, scrape, displace) rather than relying on gravity flow |
| Avoid duplicating the scoop (#2) and bistable trough (#5) | issue #12 | Concepts below explicitly do not pivot a bucket and do not rely on a snap-through flexure |

## Candidate alternatives

The list below is ordered by **risk-adjusted feasibility for a one-day
build**: passive / fully gantry-driven first, then designs that need a
single small active component, then ones that meaningfully add
electromechanical complexity.

### A. Tap-driven sieve cup (passive, gantry-as-actuator) ⭐

A printed cup (~10–20 mL) with a calibrated **mesh** or laser-precise
slot pattern in its base is mounted to the spindle clamp. The cup is
pre-loaded with powder. Cohesive powders **do not flow through the mesh
under gravity**, but each tap shakes some loose. The 3018 dispenses by
descending until the cup strikes a fixed printed anvil on the bed at a
controlled feedrate; one G-code "peck" = one tap = a near-constant micro-
dose. Total dose is metered by **tap count** (open-loop) or by an
external balance underneath (closed-loop), as recommended in
[issue #3](https://github.com/vertical-cloud-lab/powder-excavator/issues/3).

- *Mechanism in the PR #11 taxonomy*: vibratory / sieve micro-feeder,
  but **driven by gantry-impulse instead of a piezo or ERM motor** —
  removes the only active component a SWILE-class sieve dispenser would
  normally need.
- *Why it's interesting*: directly attacks the cohesive-powder regime
  (taps overcome surface forces; gravity alone cannot), keeps the
  electronics count at zero, and the only printed parts are a
  bottom-mesh cup and an anvil.
- *Risks*: tap-energy repeatability depends on Z-axis acceleration
  consistency; mesh size has to be matched to particle size (one printed
  cup per powder); needs an external balance for sub-mg accuracy.
- *Build day*: print cup + anvil (~3 h), hand-cut steel mesh insert
  (~30 min), G-code peck routine (~1 h), characterise on a 0.1 mg balance
  (~3 h).

### B. Pez-style positive-displacement chamber strip ⭐

A printed cartridge holds a row of small (e.g. 5–50 µL) **fixed-volume
chambers** in series. Each chamber is pre-loaded once, off-line, by
slot-filling and striking off the top with a flat blade (so each chamber
holds a metrologically-flat constant volume — the "loss-on-strike" idea
already used by powder-fill machines at industrial scale). To dose, the
gantry advances the cartridge one chamber-pitch using a fixed pawl on
the bed (rack-and-ratchet), bringing the next loaded chamber over the
target. A spring-loaded ejector or a fixed pin pushes the chamber's
contents downward into the vial.

- *Mechanism in the PR #11 taxonomy*: positive-displacement / volumetric
  micro-dispenser, conceptually closest to **Chemspeed SWILE** — the
  best-evidenced sub-mg head in the literature — but built from PLA and
  TPU rather than glass capillaries and pneumatics.
- *Why it's interesting*: per-dispense mass is set by chamber geometry
  (printable to ~0.05 mm with FDM, finer with resin), so once the
  packing density of a powder is calibrated, mass is repeatable without
  any feedback. Cross-contamination is bounded (each chamber is
  used once and discarded with the strip).
- *Risks*: cohesive powders may bridge over chamber openings during
  fill; open-strike accuracy is fundamentally limited by powder
  packing variance (PR #11 §4 cites < 1 % under "ideal conditions",
  much worse for cohesive solids); strip needs to be re-loaded between
  runs.
- *Build day*: design + print strip + cartridge holder + ratchet pawl
  (~4 h), print fill jig + striker bar (~1 h), characterise (~3 h).

### C. Capillary dip + fixed wiper (a printable mini-SWILE) ⭐

A short, fine-bore printed (or commercial PEEK / PTFE) **straw** is held
by the spindle clamp. The gantry dips it into a powder reservoir; the
straw fills by a combination of jamming and capillary forces. The gantry
then traverses to the dispense site and drives the straw past a fixed
**wiper / scraper** on the bed (a printed knife-edge), shearing off the
powder column into the receiving vial.

- *Mechanism in the PR #11 taxonomy*: directly the **Chemspeed SWILE**
  principle — piston-and-glass-capillary positive displacement, the
  only sub-mg head that has been benchmarked from 0.1 mg upward in
  the published evidence (PR #11 §1, §2). Replicating it in
  printable / off-the-shelf parts is exactly the "open SWILE
  alternative" gap called out in PR #11 §5.
- *Why it's interesting*: smallest doses of any concept here; entirely
  passive on the dispense side (the wiper is bolted to the bed, the
  straw is bolted to the spindle, the gantry does the rest).
- *Risks*: "fill" repeatability of an unmodulated dip is the SWILE's
  Achilles heel even in the commercial product; very fine bores will
  clog with cohesive powders; printed bores may not be smooth enough
  without a PTFE-spray finish.
- *Build day*: print straw holder + wiper + reservoir (~2 h), source
  straws / PEEK tubing from the makerspace (~1 h), characterise
  (~4 h).

### D. Brush / swab pickup + comb knock-off

A natural-bristle brush or static-dissipative microfibre swab is
clamped to the spindle. The gantry dips the brush into a powder dish;
particles adhere to the bristles by van der Waals + electrostatic
attraction (the same surface forces that make cohesive powders hard to
dose by gravity become the *mechanism* here). The gantry transports the
loaded brush to the dispense site and drags it across a fixed printed
**comb** that mechanically knocks particles off into the target vial.

- *Mechanism in the PR #11 taxonomy*: not directly represented in the
  commercial landscape — closest analogue is the dual-arm spatula
  dispenser of Jiang et al. 2023 (PR #11 §6), but at a much smaller
  pickup mass.
- *Why it's interesting*: turns the cohesive-powder failure mode into
  the design principle; absolutely minimal hardware; very small mean
  doses (likely sub-mg).
- *Risks*: highly powder-dependent; mass per stroke probably has high
  RSD; needs external balance / weighing for any usable accuracy.
- *Build day*: print brush holder + comb + reservoir (~2 h),
  characterise (~4 h).

### E. Salt-shaker oscillation dispenser

A printed cup with a calibrated bottom slot/mesh is moved by the gantry
in a fast sinusoidal X-Y "shake" pattern over the target. Total dose is
proportional to (shake amplitude × frequency × duration). No tap
required — the side-to-side acceleration substitutes for the vertical
tap of concept A.

- *Mechanism*: gantry-driven analogue of a vibratory sieve feeder (PR
  #11 §4 cites commercial equivalents from 0.36 to 1440 g/h).
- *Why it's interesting*: smooth, continuous control of dose by time
  rather than discrete taps; no impacts on the gantry frame.
- *Risks*: GRBL feedrate / acceleration limits cap how "vibratory" the
  motion really is — the 3018 is not a piezo. Minimum stable dose may
  be tens of mg.
- *Build day*: print cup (~1 h), tune G-code shake pattern (~3 h),
  characterise (~3 h).

### F. Passive auger via rack-and-pinion against a fixed pin

A short Archimedes screw inside a printed tube is geared (printed
rack + pinion or one-way clutch) to a small linear stage on the
spindle. As the gantry pushes the stage past a fixed pin on the bed, the
pinion ratchets the screw forward by a fixed angle, positively
displacing one auger-thread of powder out of the tube tip into the
target vial.

- *Mechanism in the PR #11 taxonomy*: volumetric screw / auger feeder,
  the dominant industrial principle (Coperion K-Tron, Acrison, Schenck;
  PR #11 §3) — but here all rotation comes from gantry push, no motor.
- *Why it's interesting*: continuous and repeatable in principle; gives
  per-stroke dose set by pitch × thread cross-section.
- *Risks*: small printed augers are leaky / fragile; tolerances on
  printed gear teeth are marginal at this size; cohesive powders pack
  against the auger root; build complexity is the highest of the
  passive options.
- *Build day*: high — design and print auger + clutch + stage (~6 h),
  iterate, characterise. Risk of not finishing in one day.

### G. Add a single ERM coin motor to concept A

Identical to concept A (tap-driven sieve cup) but augmented with a
~$2 ERM "phone haptic" coin motor glued to the side of the cup, run
from a 3 V coin cell via a SPST switch (no microcontroller). The motor
provides higher-frequency vibration than the gantry tap can supply,
extending the lower bound of dose-rate and improving repeatability.

- *Why it's interesting*: best-evidence, lowest-risk way of attacking
  the cohesive-powder regime if a single active component is acceptable
  (matches the strategy already proposed in
  [issue #3 Challenge 2](https://github.com/vertical-cloud-lab/powder-excavator/issues/3#issue-anti-adhesion)).
- *Risks*: introduces one battery / motor / switch — the smallest
  possible deviation from "fully passive". Vibration amplitude is
  fixed; closed-loop control requires either a relay or an MCU.

### H. Solenoid-tapped sieve (closed-loop tap)

Concept A but with a 5 V push-pull solenoid replacing the gantry tap,
fired by a microcontroller against an external balance reading. This is
the most accurate path here but also the most "electronics-heavy", and
duplicates much of what a Quantos already does — likely not worth the
build-day risk on day-of-workshop.

## Ranking summary (revised after Edison feedback)

The ranking below has been updated to reflect the Edison literature
critique (full text in [`edison_result.md`](./edison_result.md), task id
`c0c87f11-6e21-41a7-85dd-6ca3429e3fe3`). Edison's main correction was to
**promote concept G above concept A**: continuous ERM vibration matches
the published vibratory-sieve-chute regime (Besenhard et al. 2015 [1],
mg-scale capsule fills, with a measurable no-flow threshold at low
excitation and spillage at high excitation) much more closely than a
discrete gantry tap, whose **energy is quantized** and depends on
machine compliance. Dose-floor and RSD columns are now anchored to the
closest peer-reviewed analogues rather than to gut estimate.

| Rank | Concept | Active comps. | Realistic min. dose (cohesive < 100 µm) | Expected RSD | Closest published analogue |
| --- | --- | --- | --- | --- | --- |
| 1 | **G. ERM-augmented sieve** | 1 (coin motor + cell) | ~0.5–2 mg open-loop; ~0.2–1 mg with weigh-and-stop | ~5–15% open-loop; ~3–10% closed-loop | Vibratory sieve–chute microdoser, Besenhard 2015 [1] |
| 2 | **A. Tap-driven sieve cup** | 0 | ~1–5 mg open-loop; ~0.5–2 mg with iterative gravimetric | ~10–30% open-loop; ~5–15% closed-loop | Same vibratory-sieve family [1] but with quantized impulse |
| 3 | **B. Pez-style chamber strip** | 0 | ~1–10 mg per cavity | ~10–25% on cohesive fines | Low-dose dosator capsule fill, Faulhammer 2014 [2,3] |
| 4 | **C. Capillary dip + wiper** | 0 | ~0.5–5 mg; possibly 0.1–1 mg with iteration | ~8–20% (worse on cohesive) | Manual PowderPicking, Alsenz 2011 [4] — 0.6–25 mg, ~6 % CV |
| 5 | E. Salt-shaker oscillation | 0 | ~1–10 mg | ~15–40% open-loop | Same vibratory sieve family but less controlled [1] |
| 6 | F. Passive auger | 0 | ~2–20 mg per stroke | ~10–30% (bridging dominates) | Cohesive-powder feeder failure modes, Hou 2024 [5], Besenhard 2017 [6] |
| 7 | D. Brush pickup + comb | 0 | ~0.1–2 mg "transferred" | ~20–100 % | No clear peer-reviewed analogue retrieved |
| 8 | **H. Solenoid + balance** | 2+ (solenoid, MCU) | ~0.1–1 mg | ~1–5 % once tuned | Closed-loop vibratory sieve [1]; intent matches Quantos workflow |

**Recommended for the one-day build (revised):** lead with concept **G**
(tap-driven sieve cup + a single ~$2 ERM coin motor on a coin cell), and
keep concept **A** as the parallel-track fully-passive backup so that if
the ERM hardware is unavailable or fails, the same printed cup runs
unchanged off gantry-tap impulses. Concept **B** (Pez chamber strip)
remains a useful third track because it can be characterised on a
benchtop balance even when the 3018 isn't free. Edison's evidence does
**not** support our earlier instinct that A alone was the strongest
candidate — going from a single tap to continuous-but-bounded vibration
is what gives access to the documented sub-mg vibratory-sieve operating
window.

> **Preliminary design** for both A and G (single parametric SCAD
> source, printable today, with a bed-mounted anvil for A) is at
> [`../preliminary-design-sieve-cup.md`](../preliminary-design-sieve-cup.md);
> printable parts live in [`../../cad/`](../../cad/).

## Build mitigations carried over from the Edison citations

These come directly from the failure modes the cited papers attribute to
each archetype, so the one-day prototypes should bake them in from the
start:

- **A / E / G / H (sieve / shaker family).** Design the printed cup so
  the **excitation amplitude is adjustable** — Besenhard et al. show a
  hard no-flow threshold at low amplitude and spillage at high
  amplitude [1], so an adjustable mount (e.g. set-screw preload on the
  ERM, swappable anvil heights for A) is more important than nominal
  amplitude. Make the bottom mesh **swappable per powder**, and add a
  way to **re-level the powder bed** between runs — bed condition
  mattered even in lab vibratory-sieve-chute systems [1].
- **C (capillary + wiper).** Copy the three explicit mitigations that
  let manual PowderPicking reach ~6 % CV [4]: (i) tap / compact the
  source bed before each pick, (ii) take **multiple** insertions
  ("picking") per dispense rather than relying on a single fill, (iii)
  include an explicit external-tip wipe step *before* the shear-off
  wipe over the target.
- **B / F (cavity strip and passive auger).** Assume cohesive sub-100-µm
  powders will become **non-volumetric** — Faulhammer's "Group II"
  regime [2,3] — and will form plugs / arches at small geometries.
  Either restrict use of these concepts to better-flowing powders, or
  add a compaction / vibratory-conditioning step to the fill process.

## Additional alternatives surfaced by the Edison critique

Edison flagged six further micro-dose primitives we hadn't enumerated
that meet the same gantry / one-day / 3D-print-friendly constraints.
They are listed here for completeness; none are prioritised for this
workshop because each adds either non-trivial electronics or non-
trivial EHS handling, but they are worth tracking for follow-on work.

- **I. Electrostatic pickup / release wand.** A high-voltage,
  low-current electrode behind a dielectric tip charges to attract
  powder and discharges (or reverses) to release. Can plausibly reach
  the µg–sub-mg regime by making cohesive adhesion *controllable*
  rather than a nuisance. Cost: HV electronics, contamination, humidity
  sensitivity.
- **J. Tribo-electric "spray" / puff deposition.** Tribo-charge in a
  small channel and release a charged plume onto a grounded target.
  Microgram-scale possible; cost is airborne-dust / EHS handling.
- **K. Carrier-particle assisted magnetic dispensing.** Blend the
  cohesive powder with a known mass fraction of ferromagnetic carrier
  beads, then magnetically pick a controlled count of beads (each
  carrying a known small powder fraction). Converts a cohesive-powder
  problem into a coarse-particle problem; cost: changes the formulation
  and adds a segregation risk.
- **L. Gas-pulse micro-hopper.** A small chamber with an orifice and a
  squeeze-bulb / solenoid valve fires a calibrated pressure pulse to
  break arches and eject a small quantity. Can be made *passive* if the
  gantry compresses the bulb against a fixed feature.
- **M. Vacuum pick-and-place "suction dosator".** Pull a small powder
  plug into a tip with vacuum from a cheap diaphragm pump; mechanically
  eject at the target. Closer to true dosator physics than concept C.
- **N. Adhesive PDMS / tape stamp.** Pick a thin powder layer onto a
  controlled-area sticky pad; release by contact transfer. Very fast
  prototyping; poor quantitative repeatability and contamination risk.
- **O. Meltable-binder micro-pelletization.** Briefly contact powder
  with a tiny molten-wax droplet (or heated tip) so a reproducible
  pellet adheres; deposit pellet at the target. Turns the cohesive
  powder into a handled solid; cost: chemistry compatibility and
  heating hardware.

## Where this leaves the sub-10 mg cohesive-powder gap

Mapping back to the gap statement in PR #11 §5:

- **Most plausible one-day gap-closers:** **G** and **H**, because the
  vibratory-sieve operating window has been quantitatively characterised
  in the low-mg regime with a definable amplitude window and a
  closed-loop overshoot-prevention strategy [1]. **G** is the
  one-day-friendly path; **H** is the accuracy-maximising but
  electronics-heavy path.
- **Partial gap-closers:** **A** and **C**, especially when paired with
  iterative gravimetric ("dose, weigh, top-up") control. A leverages the
  same vibratory physics with cruder excitation [1]; C inherits the
  0.6 mg manual lower bound demonstrated by PowderPicking [4].
- **Unlikely to close the gap on their own:** **B**, **D**, **E**, **F**
  on cohesive sub-100-µm powders without added vibratory conditioning,
  compaction control, anti-static, or closed-loop weighing.

## Edison feedback query

A single Edison **literature** query was submitted (don't-wait policy,
per the issue) and has been fetched. Artefacts:

- [`edison_query.json`](./edison_query.json) — submitted task id
  `c0c87f11-6e21-41a7-85dd-6ca3429e3fe3`, prompt, and submission
  timestamp.
- [`edison_result.md`](./edison_result.md) — full formatted answer with
  inline citations.
- [`edison_result.json`](./edison_result.json) — raw API response.
- [`fetch_edison_result.py`](./fetch_edison_result.py) — re-fetch script
  used to produce the two files above.

## References (from the Edison answer)

1. Besenhard, M.O. *et al.* "Accuracy of micro powder dosing via a
   vibratory sieve-chute system." *Eur. J. Pharm. Biopharm.* 94,
   264–272 (2015). DOI: [10.1016/j.ejpb.2015.04.037](https://doi.org/10.1016/j.ejpb.2015.04.037).
2. Faulhammer, E. *et al.* "Low-dose capsule filling of inhalation
   products: critical material attributes and process parameters."
   *Int. J. Pharm.* 473, 617–626 (2014). DOI: [10.1016/j.ijpharm.2014.07.050](https://doi.org/10.1016/j.ijpharm.2014.07.050).
3. Faulhammer, E. *et al.* "Effect of process parameters and powder
   properties on low-dose dosator capsule filling."
4. Alsenz, J. "PowderPicking: an inexpensive, manual, medium-throughput
   method for powder dispensing." *Powder Technology* 209, 152–157
   (2011). DOI: [10.1016/j.powtec.2011.02.014](https://doi.org/10.1016/j.powtec.2011.02.014).
5. Hou, P. C-H. "Development of a micro-feeder for cohesive
   pharmaceutical powders." Dissertation (2024). DOI: [10.48730/4gp7-jb67](https://doi.org/10.48730/4gp7-jb67).
6. Besenhard, M.O. *et al.* "Micro-feeding and dosing of powders via a
   small-scale powder pump." *Int. J. Pharm.* 519, 314–322 (2017).
   DOI: [10.1016/j.ijpharm.2016.12.029](https://doi.org/10.1016/j.ijpharm.2016.12.029).
7. Jiang, Y. *et al.* "Autonomous biomimetic solid dispensing using a
   dual-arm robotic manipulator." *Digital Discovery* 2, 1733–1744
   (2023). DOI: [10.1039/d3dd00075c](https://doi.org/10.1039/d3dd00075c).

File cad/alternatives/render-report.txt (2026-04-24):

A tap-sieve: admesh[parts=None, bad_edges=0, deg=0, fix_edges=0, facets_removed=0] | prusa-slicer: ok (6344181 B)
B pez-strip: admesh[parts=None, bad_edges=0, deg=0, fix_edges=0, facets_removed=0] | prusa-slicer: ok (5963348 B)
C capillary-wiper: admesh[parts=None, bad_edges=0, deg=0, fix_edges=0, facets_removed=0] | prusa-slicer: ok (6697827 B)
D brush-comb: admesh[parts=None, bad_edges=0, deg=0, fix_edges=0, facets_removed=0] | prusa-slicer: ok (6059824 B)
E shaker: admesh[parts=None, bad_edges=0, deg=0, fix_edges=0, facets_removed=0] | prusa-slicer: ok (6990599 B)
F passive-auger: admesh[parts=None, bad_edges=0, deg=0, fix_edges=0, facets_removed=0] | prusa-slicer: ok (10385596 B)
G erm-sieve: admesh[parts=None, bad_edges=0, deg=0, fix_edges=0, facets_removed=0] | prusa-slicer: ok (7491285 B)
H solenoid-sieve: admesh[parts=None, bad_edges=0, deg=0, fix_edges=0, facets_removed=0] | prusa-slicer: ok (6814662 B)

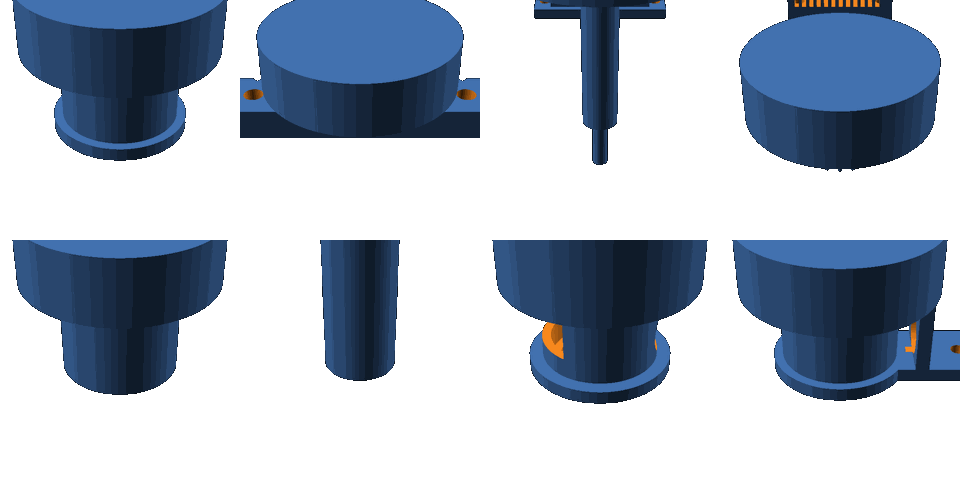
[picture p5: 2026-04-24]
cad/alternatives/composite-spin.gif

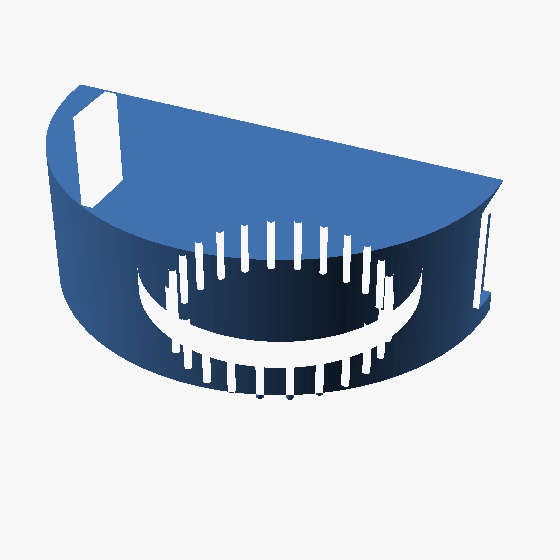
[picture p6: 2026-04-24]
cad/alternatives/D-brush-comb-cutaway.png

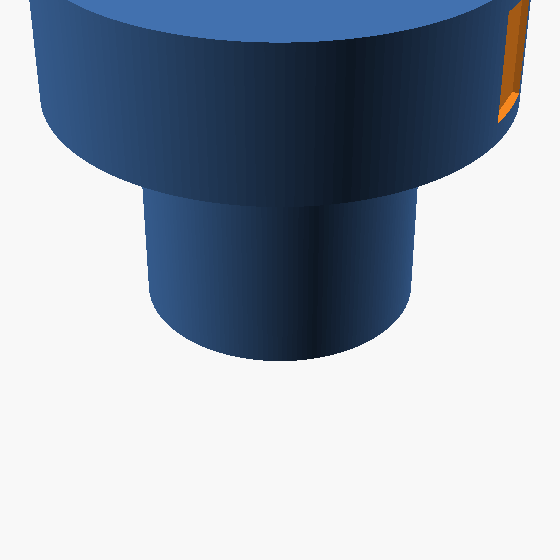
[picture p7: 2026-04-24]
cad/alternatives/E-shaker-iso.png

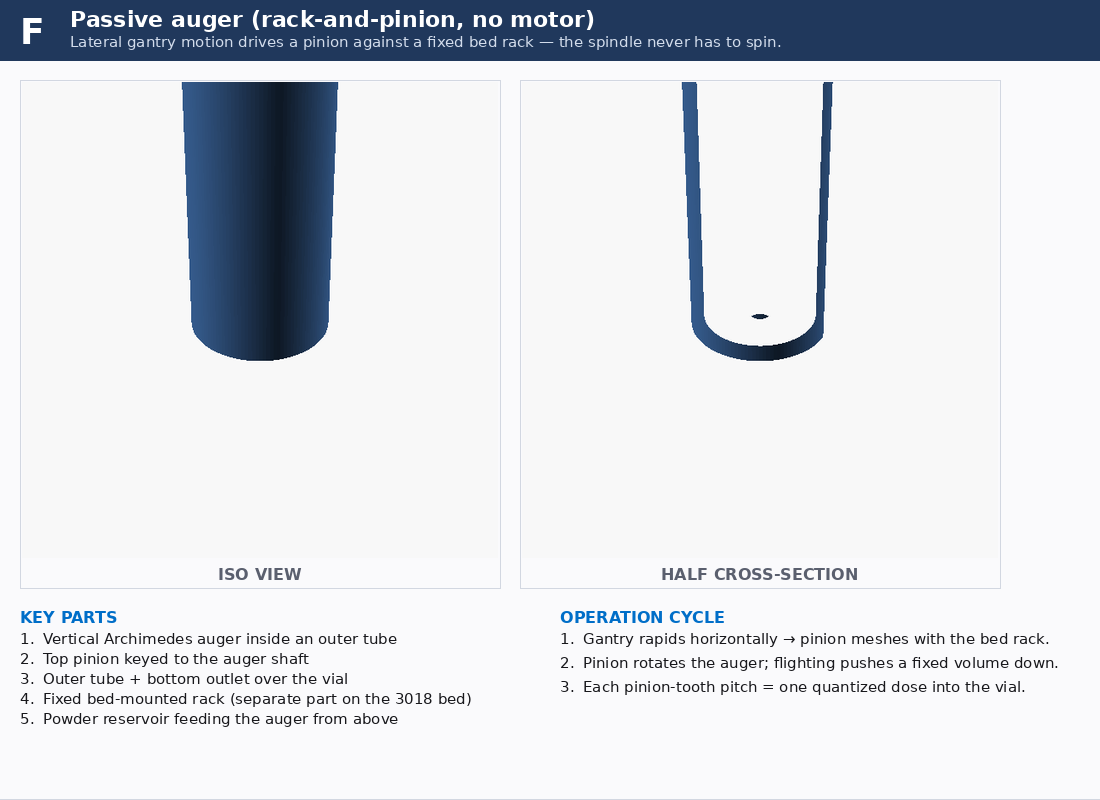
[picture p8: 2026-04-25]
cad/alternatives/F-passive-auger-panel.png

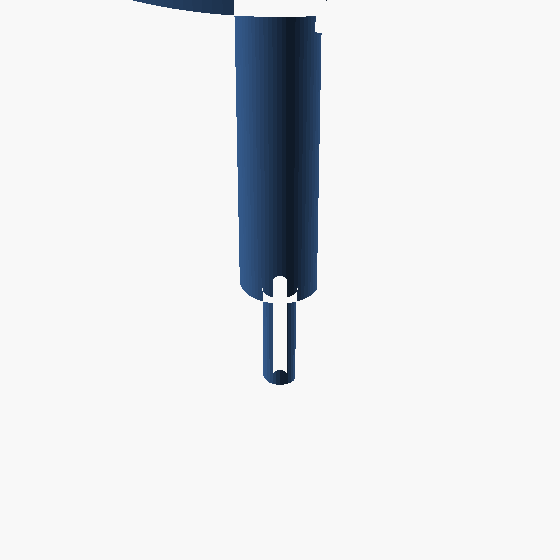
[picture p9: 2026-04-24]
cad/alternatives/C-capillary-wiper-cutaway.png

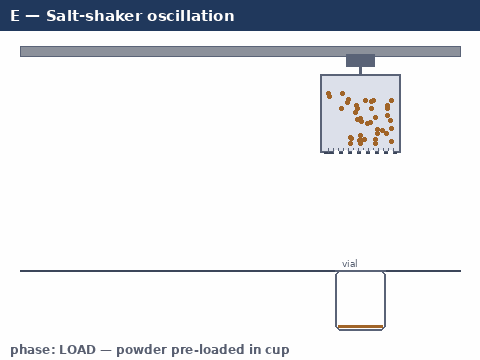
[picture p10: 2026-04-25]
cad/alternatives/E-shaker-animation.gif

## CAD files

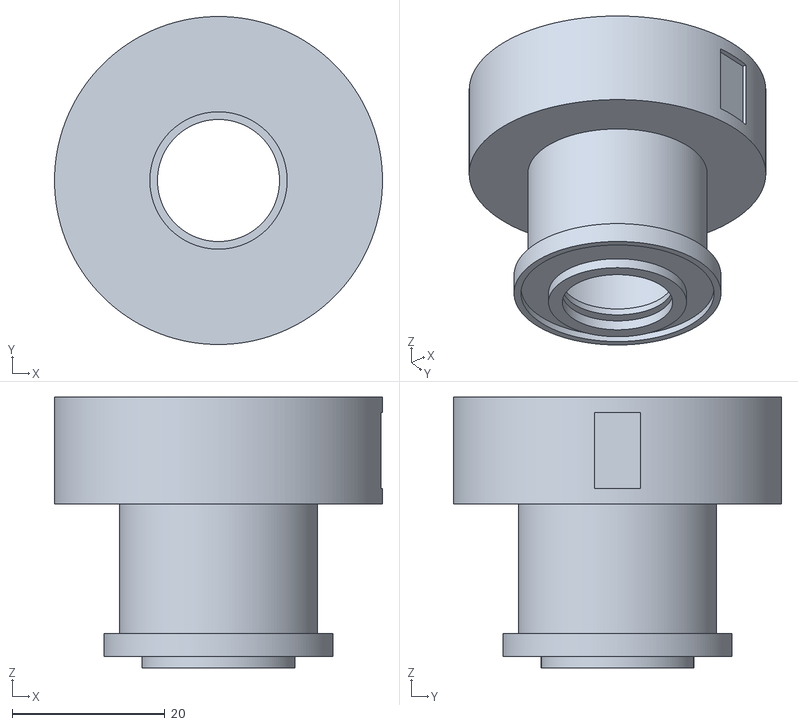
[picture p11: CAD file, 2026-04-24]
cad/alternatives/A-tap-sieve.stl
43.0 x 43.0 x 35.5

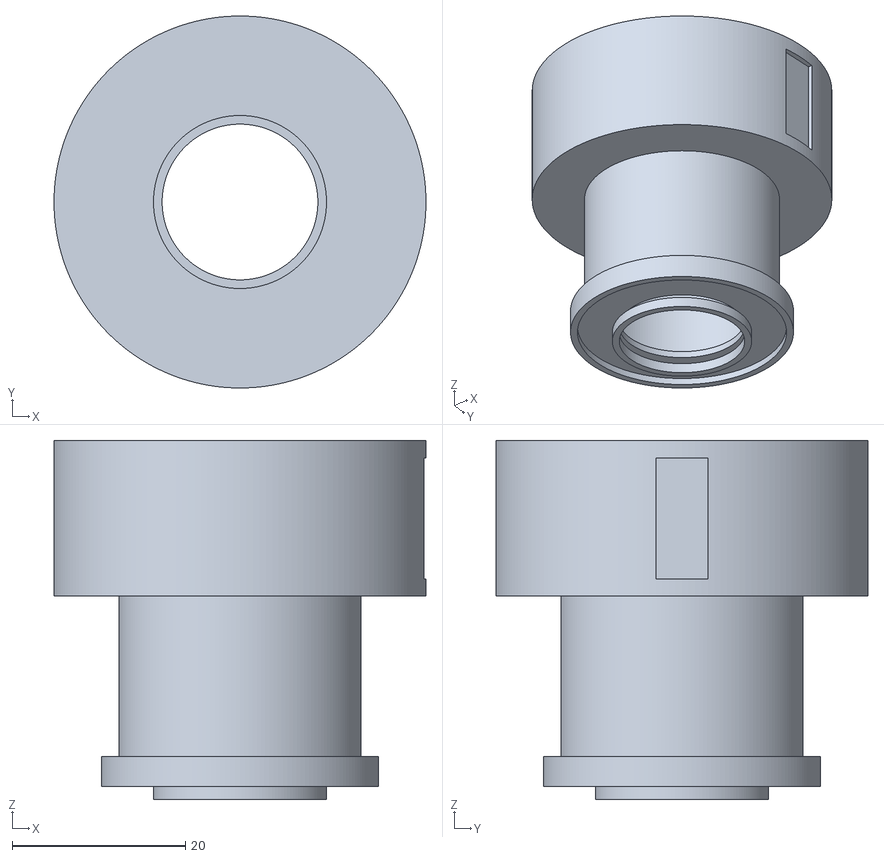
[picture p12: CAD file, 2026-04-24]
cad/sieve-cup.stl
43.0 x 43.0 x 41.5

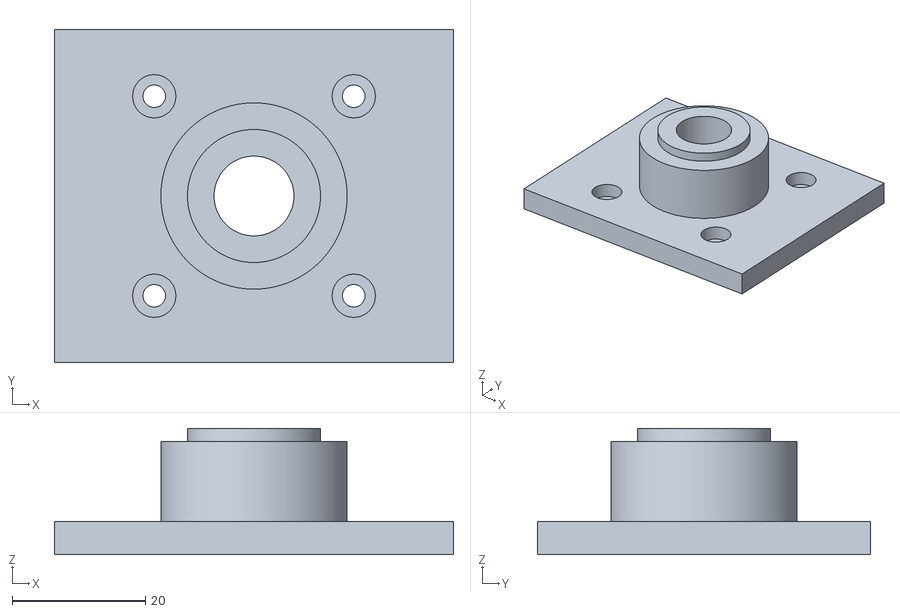
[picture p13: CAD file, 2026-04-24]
cad/tap-anvil.stl
60.0 x 50.0 x 19.0

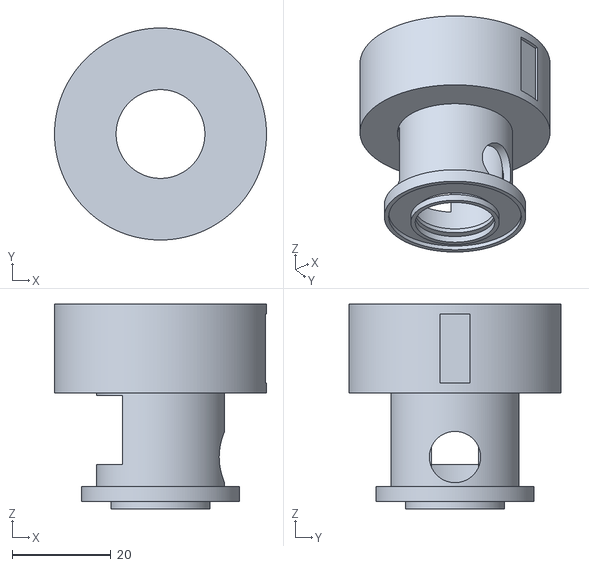
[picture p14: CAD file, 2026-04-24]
cad/alternatives/G-erm-sieve.stl
43.0 x 43.0 x 41.5

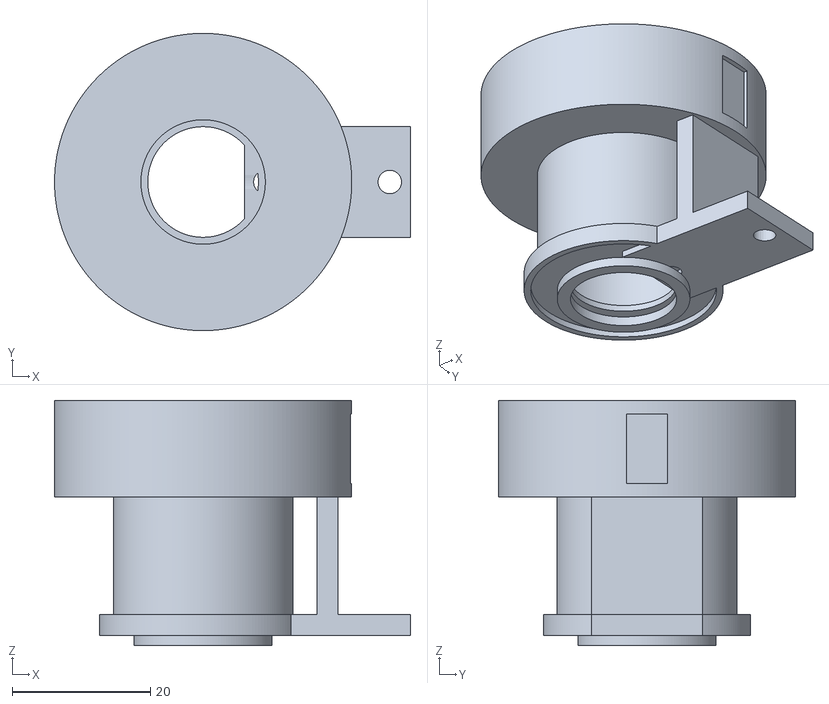
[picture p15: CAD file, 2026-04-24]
cad/alternatives/H-solenoid-sieve.stl
51.5 x 43.0 x 35.5

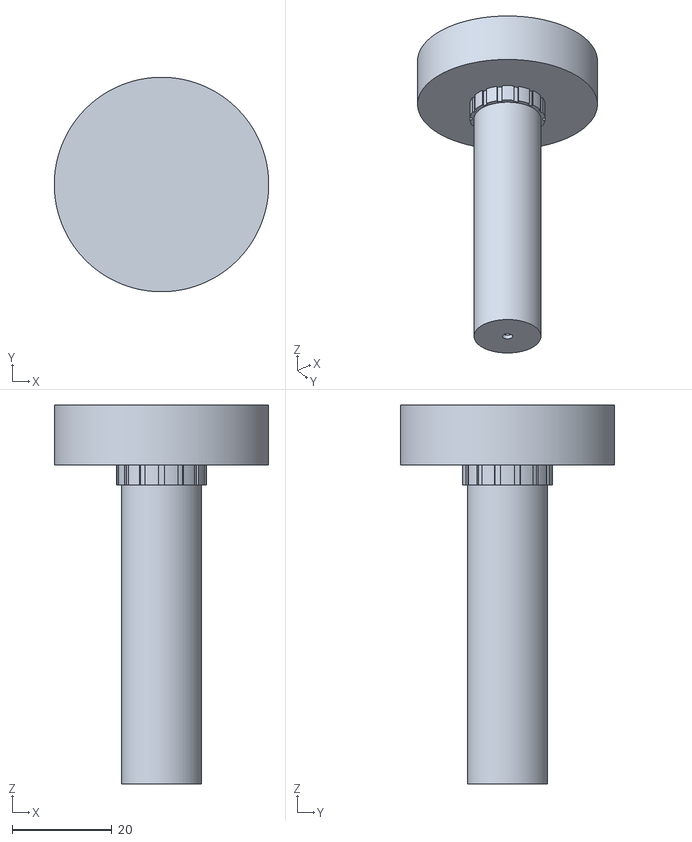
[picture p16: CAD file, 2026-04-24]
cad/alternatives/F-passive-auger.stl
43.0 x 43.0 x 76.0

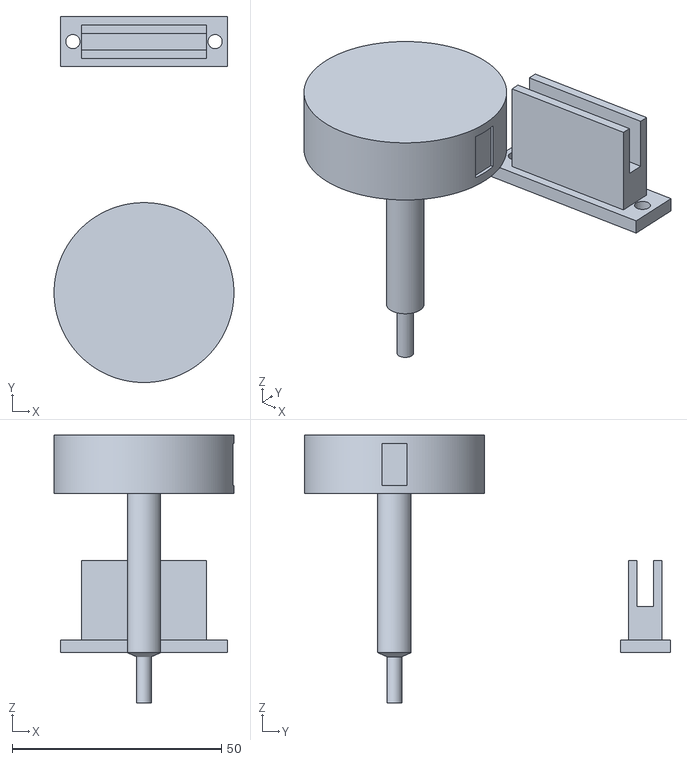
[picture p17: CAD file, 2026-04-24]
cad/alternatives/C-capillary-wiper.stl
43.0 x 87.5 x 64.0

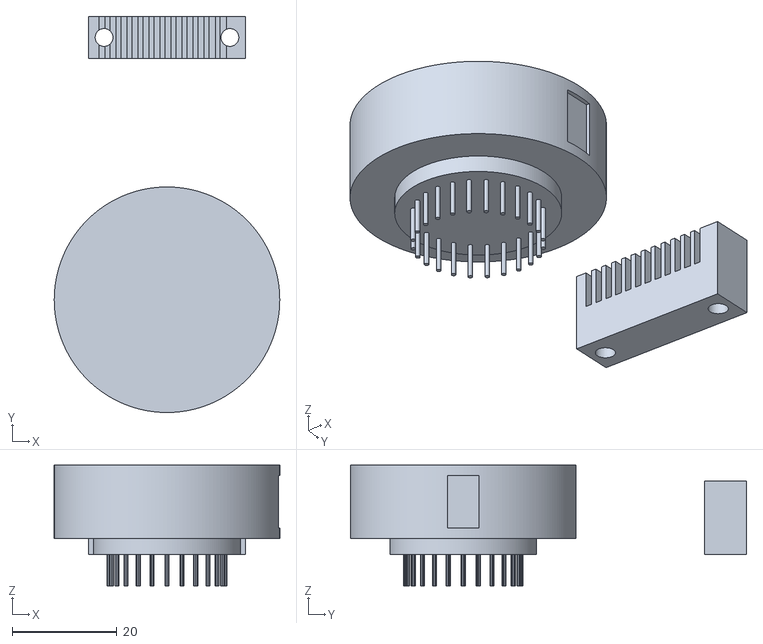
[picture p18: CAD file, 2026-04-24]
cad/alternatives/D-brush-comb.stl
43.0 x 75.5 x 23.0

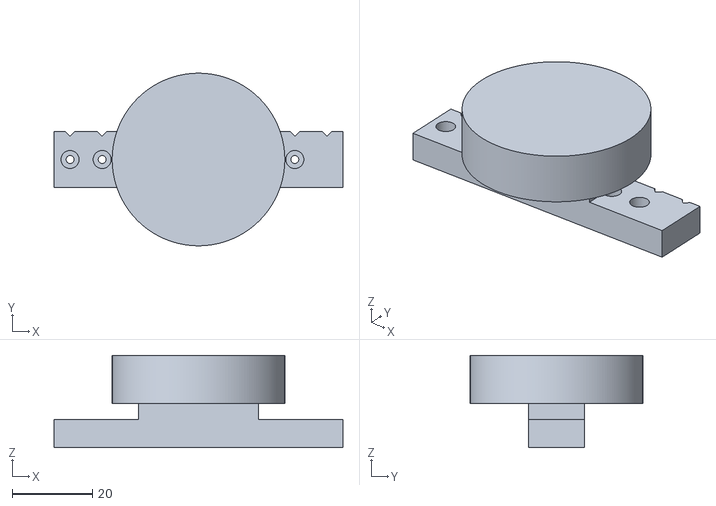
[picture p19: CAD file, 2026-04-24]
cad/alternatives/B-pez-strip.stl
72.0 x 43.0 x 23.0

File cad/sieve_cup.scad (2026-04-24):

// =====================================================================
// sieve_cup.scad
// ---------------------------------------------------------------------
// Parametric, monolithic 3D-printable sieve cup for the top-ranked
// alternative powder-dosing concepts in
// docs/alternative-dosing/brainstorm.md:
//
//   Concept A — Tap-driven sieve cup (passive, gantry-as-actuator).
//     Mounts on the Genmitsu 3018-Pro V2 spindle clamp; loaded with
//     cohesive powder; the gantry pecks the cup downward against a
//     fixed printed anvil on the bed (cad/tap_anvil.scad), and each
//     tap "snaps" a near-constant micro-dose through the bottom mesh.
//
//   Concept G — Same cup augmented with a single ~$2 ERM coin
//     vibration motor on a 3 V coin cell. Continuous bounded
//     vibration replaces the quantized gantry-tap impulse and matches
//     the published vibratory-sieve-chute regime (Besenhard et al.
//     2015, Eur. J. Pharm. Biopharm. 94, 264-272).
//
// One parametric body covers BOTH concepts: ``erm_motor_pocket = true``
// adds a side pocket sized for a 10 mm dia. x 3.4 mm coin ERM and a
// CR2032 coin-cell holder; ``false`` renders the fully-passive cup of
// concept A.
//
// The base ring carries a swappable polyester / stainless mesh
// (clamped between the cup and a screw-on retainer) so a single cup
// can be re-tuned for different powders by changing the mesh — the
// "swappable mesh" mitigation called out in the Edison literature
// critique (docs/alternative-dosing/edison_result.md).
//
// Render to STL from the CLI (no GUI required):
//
//     openscad -o cad/sieve-cup.stl \
//         -D 'erm_motor_pocket=false' cad/sieve_cup.scad
//
//     openscad -o cad/sieve-cup-erm.stl \
//         -D 'erm_motor_pocket=true' cad/sieve_cup.scad
//
// Render an isometric preview PNG:
//
//     openscad -o cad/sieve-cup-iso.png \
//         --imgsize=1100,800 --camera=0,0,18,55,0,25,260 \
//         --colorscheme=Tomorrow \
//         -D 'erm_motor_pocket=false' cad/sieve_cup.scad
//
// Tested with OpenSCAD 2021.01.
// =====================================================================

// ---------- Cup body --------------------------------------------------
cup_id            = 24.0;   // inside diameter of the powder reservoir [mm]
cup_wall          =  2.0;   // cup side-wall thickness                  [mm]
cup_height        = 22.0;   // overall cup height (powder column)       [mm]
cup_floor_thick   =  2.0;   // thickness of the mesh-clamping floor ring[mm]
mesh_window_d     = 18.0;   // open dia. through which mesh dispenses   [mm]
mesh_relief_h     =  1.0;   // recess depth that captures the mesh disc [mm]

// ---------- Anti-bridging fillet at the powder-mesh interface --------
// A small chamfered cone inside the cup biases powder toward the centre
// of the mesh window so the periphery does not arch / rathole. This
// is the "design for an adjustable excitation window + re-levelable
// powder bed" build mitigation from Besenhard 2015.
inner_cone_h      =  3.0;   // height of the powder-funneling cone      [mm]

// ---------- Spindle-clamp boss ---------------------------------------
// The Genmitsu 3018-Pro V2 spindle clamp accepts a Ø 52 mm (or, for
// some revisions, Ø 43 / 45 mm) cylindrical shank. A short cylindrical
// boss on top of the cup is the single grip surface; flats let the
// clamp's set-screws bite without crushing the powder reservoir.
boss_d            = 43.0;   // boss outer diameter                      [mm]
boss_h            = 18.0;   // boss height (length the clamp grips)     [mm]
boss_flat_w       =  6.0;   // width of the wrench-flat on the boss     [mm]
boss_flat_depth   =  0.8;   // depth of the wrench-flat                 [mm]

// Vent across the boss top so loading powder doesn't trap air.
boss_vent_d       =  3.0;   // vent hole diameter                       [mm]

// ---------- Mesh-retainer ring (printed; threaded onto cup base) -----
// We don't print the retainer here (it's a separate trivial ring); we
// just expose the female pocket geometry where the mesh is captured.
retainer_pocket_d = 32.0;   // OD pocket for the retainer ring          [mm]
retainer_pocket_h =  3.5;   // depth of the retainer pocket             [mm]

// ---------- Anvil-strike target -------------------------------------
// The base of the cup gets a short standoff annular pad — sized for
// the anvil's printed pad — that takes the impact when the gantry
// pecks the cup against cad/tap_anvil.scad. Annular (not solid) so
// the mesh window stays free; the shock travels through the cup wall
// rather than the mesh disc.
//
// NOTE: ``strike_pad_d`` is the *inner reference* diameter of the
// annulus; the actual strike-pad OD is ``strike_pad_d + 6.0`` (so
// 20 mm with the default 14 mm), matched to the 20 mm anvil strike
// face in cad/tap_anvil.scad (``strike_face_od = 20``).
strike_pad_d      = 14.0;   // inner reference dia. (OD = +6 mm)        [mm]
strike_pad_h      =  1.5;   // strike pad standoff below the floor      [mm]

// ---------- ERM motor pocket (concept G only) ------------------------
// Sized for a stock 10 mm dia. x 3.4 mm coin ERM (e.g. Vybronics
// VC1034B202F, Adafruit 1201). Flat back, two solder pads on one
// face. The pocket is open on the outer face so the ERM can be glued
// in with a dab of cyanoacrylate after wires are routed.
//
// A second pocket alongside it accepts a CR2032 coin-cell holder
// (20 mm dia. x 4 mm, e.g. Keystone 1066) wired through a SPST switch
// glued to a third small flat. No microcontroller is required for the
// "open-loop G" build documented in the brainstorm.
erm_motor_pocket  = false;

erm_pocket_d      = 10.4;   // ERM pocket dia. (with print clearance)   [mm]
erm_pocket_h      =  3.6;   // ERM pocket depth                         [mm]
erm_pocket_z      =  9.0;   // height of pocket centre above cup base   [mm]

cell_pocket_w     = 21.0;   // CR2032 holder pocket width               [mm]
cell_pocket_h     = 14.0;   // CR2032 holder pocket height              [mm]
cell_pocket_d     =  5.5;   // CR2032 holder pocket depth into wall     [mm]
cell_pocket_z     = 14.5;   // height of pocket centre above cup base   [mm]

// Small wire-routing relief from the ERM pocket up to the boss vent so
// the lead wires stay clear of the gantry clamp.
wire_relief_w     =  1.6;   // wire-relief slot width                   [mm]
wire_relief_d     =  1.6;   // wire-relief slot depth into the wall     [mm]

// ---------- Render quality ------------------------------------------
$fa = 2;        // facet angle [deg]
$fs = 0.4;      // facet size  [mm]

// =====================================================================
// Sub-assemblies
// =====================================================================

module cup_body() {
    difference() {
        // outer cup + base flange (mesh-retainer pocket) + strike pad
        union() {
            cylinder(d = cup_id + 2 * cup_wall, h = cup_height);
            cylinder(d = retainer_pocket_d,     h = retainer_pocket_h);
            // strike pad sits below the floor as a continuation of
            // the cup body; declared inside the union so the booleans
            // apply consistently and the part stays a single volume.
            translate([0, 0, -strike_pad_h])
                cylinder(d = strike_pad_d + 6.0, h = strike_pad_h);
        }
        // inner reservoir
        translate([0, 0, cup_floor_thick])
            cylinder(d = cup_id, h = cup_height);
        // mesh window through the floor and strike pad
        translate([0, 0, -strike_pad_h - 0.1])
            cylinder(d = mesh_window_d,
                     h = cup_floor_thick + mesh_relief_h
                         + strike_pad_h + 0.2);
        // recess to capture the mesh disc on the underside (above floor only)
        translate([0, 0, 0])
            cylinder(d = retainer_pocket_d - 2.0,
                     h = mesh_relief_h);
        // powder-funneling cone (anti-bridging) inside the cup
        translate([0, 0, cup_floor_thick - 0.01])
            cylinder(d1 = mesh_window_d + 4.0,
                     d2 = mesh_window_d,
                     h  = inner_cone_h);
    }
}
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

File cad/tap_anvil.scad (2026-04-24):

// =====================================================================
// tap_anvil.scad
// ---------------------------------------------------------------------
// Bed-mounted anvil for concept A (tap-driven sieve cup) of the
// alternative powder-dosing brainstorm in
// docs/alternative-dosing/brainstorm.md.
//
// The Genmitsu 3018-Pro V2 gantry "pecks" cad/sieve_cup.scad downward
// onto this anvil at a controlled feedrate. Each peck is one tap;
// each tap shakes a roughly-constant micro-dose through the sieve
// mesh into the target vial below. The anvil's only job is to provide
// a hard, repeatable, *fixed* impact surface; the dose receiver (vial)
// sits in the bore that runs through the anvil's centre.
//
// Geometry rationale:
//
//   - Strike face is an annular pad whose OD matches the cup's
//     ``strike_pad_d + 6 mm`` ring (default 20 mm OD), with a clear
//     bore through the middle so the powder-stream from the mesh
//     window passes straight through into the receiving vial.
//   - Four M3 holes on a 30 x 30 mm pattern bolt the anvil to the
//     T-slot bed plate using standard 3018 hold-down clamps.
//   - The strike face is intentionally raised on a short pillar so
//     spilled powder cannot accumulate at the impact line.
//
// Render to STL from the CLI (no GUI required):
//
//     openscad -o cad/tap-anvil.stl cad/tap_anvil.scad
//
// Render an isometric preview PNG:
//
//     openscad -o cad/tap-anvil-iso.png \
//         --imgsize=1100,800 --camera=0,0,8,55,0,25,200 \
//         --colorscheme=Tomorrow cad/tap_anvil.scad
//
// Tested with OpenSCAD 2021.01.
// =====================================================================

// ---------- Parameters ----------------------------------------------
base_x          = 60.0;    // base footprint along x                   [mm]
base_y          = 50.0;    // base footprint along y                   [mm]
base_thick      =  5.0;    // base plate thickness                     [mm]

mount_hole_d    =  3.4;    // M3 clearance                             [mm]
mount_hole_dx   = 30.0;    // hole pitch along x                       [mm]
mount_hole_dy   = 30.0;    // hole pitch along y                       [mm]
counterbore_d   =  6.5;    // M3 cap-screw counterbore diameter        [mm]
counterbore_h   =  3.0;    // counterbore depth                        [mm]

pillar_d        = 28.0;    // pillar OD around the strike face         [mm]
pillar_h        = 12.0;    // height of the pillar above the base      [mm]

strike_face_od  = 20.0;    // strike face OD (matches cup pad)         [mm]
strike_face_id  = 12.0;    // central bore for the dispensed powder    [mm]
strike_face_h   =  2.0;    // raised lip of the strike pad             [mm]

vial_collar_d   = 16.5;    // collar diameter to locate a 15 mm vial   [mm]
vial_collar_h   =  4.0;    // collar depth                             [mm]

// ---------- Render quality ------------------------------------------
$fa = 2;
$fs = 0.4;

// =====================================================================
// Sub-assemblies
// =====================================================================

module base_plate() {
    difference() {
        translate([-base_x / 2, -base_y / 2, 0])
            cube([base_x, base_y, base_thick]);
        // M3 mounting holes with counterbores from the top
        for (sx = [-1, 1]) for (sy = [-1, 1])
            translate([sx * mount_hole_dx / 2,
                       sy * mount_hole_dy / 2, -0.1]) {
                cylinder(d = mount_hole_d, h = base_thick + 0.2);
                translate([0, 0, base_thick - counterbore_h + 0.1])
                    cylinder(d = counterbore_d,
                             h = counterbore_h + 0.2);
            }
        // central vial bore
        translate([0, 0, -0.1])
            cylinder(d = vial_collar_d, h = vial_collar_h + 0.1);
        translate([0, 0, vial_collar_h - 0.01])
            cylinder(d = strike_face_id,
                     h = base_thick - vial_collar_h + 0.2);
    }
}

module pillar() {
    difference() {
        translate([0, 0, base_thick])
            cylinder(d = pillar_d, h = pillar_h);
        translate([0, 0, base_thick - 0.01])
            cylinder(d = strike_face_id, h = pillar_h + 0.1);
    }
}

module strike_pad() {
    difference() {
        translate([0, 0, base_thick + pillar_h])
            cylinder(d = strike_face_od, h = strike_face_h);
        translate([0, 0, base_thick + pillar_h - 0.1])
            cylinder(d = strike_face_id,
                     h = strike_face_h + 0.2);
    }
}

// =====================================================================
// Top-level assembly
// =====================================================================

module tap_anvil() {
    color([0.55, 0.65, 0.85]) base_plate();
    color([0.85, 0.85, 0.88]) pillar();
    color([0.95, 0.55, 0.45]) strike_pad();
}

tap_anvil();

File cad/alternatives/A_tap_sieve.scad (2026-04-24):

// =====================================================================
// alternatives/A_tap_sieve.scad — Tap-driven sieve cup (passive)
// ---------------------------------------------------------------------
// Concept A from docs/alternative-dosing/brainstorm.md.
//
// Mounts on the 3018-Pro V2 spindle clamp; the gantry pecks the cup
// downward against a fixed printed anvil — each impact dislodges a
// near-constant micro-dose through the bottom mesh.
//
// One-piece printable; mesh disc is a separate consumable cut from
// polyester sieve cloth and clamped by a press-fit retainer ring (not
// rendered here; identical to the one in cad/sieve_cup.scad).
// =====================================================================

$fa = 2; $fs = 0.4;

// --- Parameters (mm) -------------------------------------------------
boss_d        = 43;     // 3018-Pro V2 spindle-clamp grip diameter
boss_h        = 14;
boss_flat_w   = 6;
boss_flat_d   = 0.8;
cup_id        = 22;
cup_wall      = 2.0;
cup_h         = 20;
floor_h       = 2.0;
mesh_d        = 16;     // open dispensing window
retainer_pkt_d = 30;
retainer_pkt_h = 3.0;
strike_pad_id = 14;
strike_pad_od = 20;     // matches anvil strike face
strike_pad_h  = 1.5;
cone_h        = 3.0;    // anti-bridging funnel inside the cup

module a_cup() {
    difference() {
        union() {
            // boss
            translate([0, 0, cup_h])
                cylinder(d = boss_d, h = boss_h);
            // cup body
            cylinder(d = cup_id + 2*cup_wall, h = cup_h);
            // base flange / retainer pocket
            cylinder(d = retainer_pkt_d, h = retainer_pkt_h);
            // strike pad
            translate([0, 0, -strike_pad_h])
                cylinder(d = strike_pad_od, h = strike_pad_h);
        }
        // wrench-flats on boss
        for (sx = [-1, 1])
            translate([sx*(boss_d/2 - boss_flat_d), -boss_flat_w/2, cup_h+2])
                cube([boss_flat_d+0.5, boss_flat_w, boss_h-4]);
        // hollow boss
        translate([0, 0, cup_h - 0.01])
            cylinder(d = cup_id - 4, h = boss_h + 0.1);
        // reservoir
        translate([0, 0, floor_h])
            cylinder(d = cup_id, h = cup_h);
        // mesh window (through floor and strike pad)
        translate([0, 0, -strike_pad_h - 0.1])
            cylinder(d = mesh_d, h = floor_h + strike_pad_h + 0.2);
        // mesh-disc relief
        cylinder(d = retainer_pkt_d - 2, h = 1.0);
        // anti-bridging cone
        translate([0, 0, floor_h - 0.01])
            cylinder(d1 = mesh_d + 4, d2 = mesh_d, h = cone_h);
    }
}

a_cup();

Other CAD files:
cad/alternatives/E-shaker.stl
cad/sieve-cup-erm.stl
cad/alternatives/B_pez_strip.scad
cad/alternatives/C_capillary_wiper.scad
cad/alternatives/D_brush_comb.scad
cad/alternatives/E_shaker.scad
cad/alternatives/F_passive_auger.scad
cad/alternatives/G_erm_sieve.scad
cad/alternatives/H_solenoid_sieve.scad

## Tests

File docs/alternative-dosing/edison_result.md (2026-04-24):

Question: We are designing a small open-source powder dispensing
attachment for a Genmitsu 3018-Pro V2 desktop CNC gantry (GRBL, ~300 mm
x 180 mm x 45 mm work envelope, ~3 kg payload on the spindle clamp).
Constraints: must be buildable in roughly one workshop day, 3D printing
is fine, and adding active electromechanical components (motors,
solenoids, microcontrollers) is allowed but each one is treated as a
schedule risk. Target dose range is microgram to low-milligram on
typically cohesive (sub-100-um) inorganic and organic powders.

We have already explored two designs in detail and are looking for
feedback on **alternatives** to those two:

  Design 1 (already prototyped, see PR #2 of vertical-cloud-lab/powder-
  excavator): a 3D-printed semicircular scoop / ladle with side pins
  that catch a fixed ledge on the bed; the pins pivot the scoop and
  dump powder into a vial. Dose control via dip depth (open-loop) or
  closed-loop gravimetric.

  Design 2 (already prototyped, see PR #5 of the same repo): a bistable
  / bimodal compliant trough — a snap-through flexure that holds powder
  in one stable state and dumps it via snap-through into the other.

Please critique the following eight alternative concepts (full
descriptions in our brainstorm doc), and rank them for one-day-build
feasibility on the 3018-Pro V2, expected achievable dose floor and RSD
on cohesive powders, and risk of failure. Where vendor or academic
analogues exist (e.g. Mettler Toledo Quantos, Chemspeed SWILE / GDU-Pfd,
Coperion K-Tron, Jiang et al. 2023 dual-arm spatula, Berkeley A-Lab),
please cite them and contrast our concept with the published behaviour:

  A. Tap-driven sieve cup, where the gantry itself supplies the tap
     impulse by pecking the cup against a fixed anvil on the bed
     (no motor; sieve only releases on tap, exploiting the cohesive
     regime that defeats hopper feeders).

  B. Pez-style positive-displacement chamber strip — a printed strip
     of fixed-volume chambers, pre-loaded by strike-off, advanced one
     pitch per dispense by a fixed pawl on the bed and discharged by
     a fixed ejector. (Conceptually a printable, single-use
     SWILE-like volumetric head.)

  C. Capillary dip + fixed wiper — a fine printed straw fills by
     capillary / jamming on dip into a powder reservoir; the gantry
     drives the straw past a fixed wiper knife to shear off the
     contents into the target. (Direct printable mini-SWILE
     analogue.)

  D. Brush / swab pickup + fixed comb knock-off — natural-bristle
     pickup by van der Waals / electrostatic adhesion, deposited by
     dragging the loaded brush across a fixed comb over the target.

  E. Salt-shaker oscillation — printed cup with calibrated bottom
     mesh, dose metered by the gantry's X-Y oscillation amplitude /
     frequency / duration over the target.

  F. Passive auger via rack-and-pinion against a fixed pin — gantry
     push past a fixed pin ratchets a printed Archimedes screw inside
     a tube to positively displace one auger thread of powder per
     stroke (no motor).

  G. Tap-driven sieve (concept A) augmented with a single ~$2 ERM
     coin vibration motor on the cup, run from a coin cell via a
     SPST switch — minimal added electronics.

  H. Solenoid-tapped sieve closed-loop with an external 0.1 mg
     balance and a microcontroller — the most accurate option, but
     duplicates much of what a Quantos does and is the most
     "electronics-heavy".

Specific questions:

  1. Which of A-H are the strongest candidates for a one-day workshop
     build that is genuinely *different* from the scoop and bimodal
     trough designs above, and why?

  2. For each candidate, what is a realistic minimum dose, expected
     RSD, and dominant failure mode on cohesive sub-100-um powders?

  3. Are there published, peer-reviewed or vendor-documented designs
     for any of A-H (especially A, B, C) that we should be aware of
     and cite / borrow from rather than re-invent? Please be explicit
     when no published analogue exists.

  4. Are there *additional* alternative dispensing styles we haven't
     listed that meet the same gantry / one-day / 3D-print-friendly
     constraints? Concretely, please consider tribo-electric
     spray, electrostatic pickup wands, magnet-assisted dispensing
     (where a ferromagnetic carrier particle is mixed with the
     powder), microfluidic gas-pulse dispensing, and any other
     micro-dose primitives that may not have surfaced in the
     commercial-landscape sweep we did in PR #11 of the same repo.

  5. Where do these eight concepts sit relative to the documented
     "sub-10 mg cohesive-powder dispensing gap" identified in our
     PR #11 commercial-landscape synthesis? Which (if any) plausibly
     close that gap with a single workshop-day's effort?

## Scope and assumptions
You asked for critique and ranking of eight **alternative** powder dispensing concepts (A–H) for a Genmitsu 3018-Pro V2 CNC gantry, under a one-workshop-day build constraint, with cohesive sub‑100‑µm powders, targeting microgram to low‑mg doses. Below, “dose floor” means a **realistic** lower bound for repeatable dispenses on cohesive powders **without heroic tuning**; microgram-level performance is treated as requiring either closed-loop gravimetry or electrostatic methods.

Published quantitative data are sparse for DIY-scale mechanisms; therefore I anchor estimates to the closest peer-reviewed analogues retrieved in this run: vibratory sieve/chute microdosing studies (MG2 Microdose class) (besenhard2015accuracyofmicro pages 2-4, besenhard2015accuracyofmicro pages 4-5, besenhard2015accuracyofmicro pages 7-8), dosator low-dose filling qualification data (faulhammer2014lowdosecapsulefilling pages 1-2, faulhammerUnknownyeareffectofprocess pages 2-4), manual capillary-tip “powder picking” data (alsenz2011powderpickinganinexpensive pages 1-2), and evidence of Chemspeed dispensing failures due to clogging by compressible solids (jiang2023autonomousbiomimeticsolid pages 10-10). Where an analogue is missing, I state that explicitly.

## Executive ranking (one-day build × cohesive-powder dose floor × risk)
### Best “one-day, genuinely different” candidates
1) **G (tap/sieve + $2 ERM vibration motor)**: most likely to achieve consistent **sub‑mg to low‑mg** dosing with manageable one-day complexity, because it most closely resembles the vibratory excitation required for sieve-based microdosing and avoids the quantization problem of single impacts (besenhard2015accuracyofmicro pages 4-5). 

2) **A (gantry-tap-driven sieve cup against bed anvil)**: extremely fast to build and mechanically clean; likely useful for **~1–5 mg** cohesive doses open-loop or iterative gravimetric dosing. Main weakness is that the **energy input is quantized** (one tap) and strongly depends on machine compliance and exact contact; vibratory sieve systems show clear no‑flow thresholds at low excitation and spillage at excessive excitation (besenhard2015accuracyofmicro pages 4-5).

3) **B (Pez-style positive-displacement chamber strip)**: strong as a **workflow** primitive (pre-load off-machine; dispense many shots fast) and is genuinely different from scoop/trough. Dose floor likely **mg-class** for cohesive powders unless you can guarantee complete cavity fill/strike-off; cohesion can cause partial fill and carryover. By analogy, low-dose volumetric filling can reach <5% RSD for “Group I” powders in dosator systems, but very fine cohesive powders show non-volumetric behavior and higher RSD/plugging risk (faulhammerUnknownyeareffectofprocess pages 2-4, faulhammer2014lowdosecapsulefilling pages 1-2).

4) **C (capillary dip + fixed wiper)**: plausible path to **~0.5–5 mg** and potentially sub‑mg with iteration, but higher clogging risk on cohesive fines. The closest retrieved analogue is manual PowderPicking using positive-displacement pipettes with capillary/piston tips, which achieved **0.6–25 mg** with **~6% CV** (alsenz2011powderpickinganinexpensive pages 1-2). Automated capillary-like commercial systems can fail by clogging for some compressible solids (jiang2023autonomousbiomimeticsolid pages 10-10).

### Fast-to-build but weaker on cohesive precision
5) **E (salt-shaker XY oscillation)**: quick baseline; likely similar performance envelope to A but with more spillage/slosh sensitivity. Vibratory sieve systems demonstrate that operating space is narrow: too little excitation yields no flow; too much causes spillage (besenhard2015accuracyofmicro pages 4-5).

6) **F (passive rack-and-pinion auger)**: mechanically more involved (tolerances, sealing, backlash) and cohesion/bridging at the inlet is a standard failure mode for gravity-fed feeders (hou2024developmentofa pages 44-47). Expect mg to 10s‑mg stroke sizes unless carefully miniaturized; risk of intermittent “chunking” and overdosing is a known issue for cohesive powders (besenhard2017microfeedinganddosing pages 1-6).

### High risk for your constraints
7) **D (brush pickup + comb knock-off)**: simplest mechanically, but the metering principle (adhesion/tribo/electrostatic) is intrinsically variable; I would treat as a qualitative “transfer some powder” tool rather than quantitative dispensing unless paired with closed-loop weighing.

8) **H (solenoid-tapped sieve + external balance + MCU closed-loop)**: likely best ultimate accuracy, but highest schedule risk due to integration (balance vibration isolation, latency, tuning, software). Closed-loop stopping is used in vibratory sieve systems to prevent overshoot (besenhard2015accuracyofmicro pages 2-4), but implementing this robustly on a desktop CNC in one day is challenging.

## Comparison table (A–H)
| Concept | Mechanism archetype | One-day build feasibility | Expected realistic minimum single dose on cohesive sub-100-µm powders | Expected RSD/CV range | Dominant failure mode(s) | Closest published/vendor analogue |
|---|---|---|---|---|---|---|
| A. Tap-driven sieve cup | Passive impact-excited sieve / pepper-shaker microdoser | **High** — simplest hardware: printed cup + mesh + bed anvil; no onboard electronics, only motion programming | **~1–5 mg open-loop; ~0.5–2 mg with external gravimetric iteration**; below this, tap energy granularity and stochastic release dominate, though vibratory sieve systems show mg-scale operation (besenhard2015accuracyofmicro pages 2-4, besenhard2015accuracyofmicro pages 4-5, besenhard2015accuracyofmicro pages 2-2, besenhard2015accuracyofmicro pages 7-8) | **~10–30% open-loop; ~5–15% with closed-loop stop/iterate** | Mesh blinding, no-flow from cohesion if impulse too weak, burst release/spillage if impact too strong, bed-history sensitivity | Vibratory sieve–chute / “pepper-shaker” class, e.g. MG2 Microdose-style system; your version substitutes discrete gantry tapping for controlled vibration (besenhard2015accuracyofmicro pages 2-4, besenhard2015accuracyofmicro pages 4-5, besenhard2015accuracyofmicro pages 2-2, besenhard2015accuracyofmicro pages 7-8) |
| B. Pez-style chamber strip | Pre-metered positive-displacement cavity strip / dosing-disc analogue | **Med-High** — mechanically straightforward but dose depends on clean strike-off, cavity reproducibility, and reliable indexing/ejection | **~1–10 mg** for practical printed cavities; **sub-mg possible only with very small cavities and excellent strike-off, but high risk** | **~10–25%** on cohesive fines; can be better on freer-flowing powders | Incomplete cavity fill, inconsistent strike-off density, chamber carryover, powder sticking in chamber or ejector, pitch/index jams | Closest analogue: low-dose dosator / volumetric cavity filling; unlike dosators, strip cavities lack compression control and bed-conditioning, so expect worse cohesion robustness (faulhammerUnknownyeareffectofprocess pages 2-4, faulhammer2014lowdosecapsulefilling pages 1-2) |
| C. Capillary dip + fixed wiper | Capillary-tip / narrow-tube pickup with shear wipe; mini-SWILE-like | **Med** — printable straw plus wiper is easy, but repeatable fill of cohesive powder in a tiny tube is the hard part | **~0.5–5 mg** if tip ID is tuned and wiped well; **~0.1–1 mg may be possible experimentally** but not a safe one-day expectation | **~8–20%** if geometry is well tuned; may degrade badly on cohesive/clogging powders | Tip clogging, non-uniform fill density, outside-of-tip contamination, incomplete wipe/release, humidity/static sensitivity | Manual PowderPicking is the clearest retrieved analogue (0.6–25 mg, ~6% CV), though it uses commercial capillary-piston tips and manual tapping/wiping; Chemspeed capillary-style dispensing also shows clogging/failure on some powders (alsenz2011powderpickinganinexpensive pages 1-2, jiang2023autonomousbiomimeticsolid pages 10-10) |
| D. Brush / swab pickup + comb knock-off | Adhesion-based pickup/deposition | **High** — very easy to prototype physically, but metrology and repeatability risk are high | **~0.1–2 mg** plausible as transferred adhered mass, but strongly material- and humidity-dependent; true microgram dosing is not realistic in a one-day build | **~20–100%+** | Variable adhesion, electrostatic carryover, poor release at comb, progressive contamination/loading memory | No clear published analogue found in retrieved sources |
| E. Salt-shaker oscillation | Open-loop oscillatory shaker with bottom mesh | **High** — easy to print; uses gantry XY oscillation directly | **~1–10 mg** practically; finer doses are possible only with excellent tuning and favorable powder | **~15–40% open-loop** | Same sieve issues as A plus lateral slosh, angle sensitivity, resonance changes with fill level, spillage at high excitation | Broadly analogous to vibratory sieve/shaker microdosing, but less controlled than vertical vibratory sieve–chute systems studied in pharma (besenhard2015accuracyofmicro pages 2-4, besenhard2015accuracyofmicro pages 4-5, besenhard2015accuracyofmicro pages 7-8) |
| F. Passive auger via rack-and-pinion | Ratcheted screw/auger micro-feeder | **Med** — conceptually simple, but printed auger tolerances, backlash, sealing, and anti-bridging features are risky in one day | **~2–20 mg per stroke** realistically without active stirring; lower may be possible with very fine pitch but cohesion risk rises sharply | **~10–30%** without stirrer/LIW feedback | Bridging/ratholing at inlet, screw packing-density drift, ratchet backlash, chunking causing overdoses, jamming | Screw/auger micro-feeder family and low-dose gravimetric feeders; literature notes cohesive powders challenge screws and gravity-fed devices via bridging/ratholing/density drift (hou2024developmentofa pages 44-47, faulhammerUnknownyeareffectofprocess pages 2-4) |
| G. Tap-driven sieve + ERM motor | Vibratory sieve with onboard low-cost excitation | **Med-High** — only one added actuator; much closer to documented vibratory-sieve operating mode than A/E | **~0.5–2 mg open-loop; ~0.2–1 mg with external gravimetric stop**; best chance among simple new concepts for sub-mg class | **~5–15% open-loop after tuning; ~3–10% with closed-loop stop** | Mesh blinding, powder bed conditioning drift, over-vibration spillage, battery voltage drift, mount loosening | Strongest analogue to vibratory sieve–chute microdosing, which shows mg-scale fills, amplitude thresholds for no-flow, and spillage at excessive excitation (besenhard2015accuracyofmicro pages 2-4, besenhard2015accuracyofmicro pages 4-5, besenhard2015accuracyofmicro pages 2-2, besenhard2015accuracyofmicro pages 7-8) |
| H. Solenoid-tapped sieve closed-loop | Closed-loop gravimetric tapped/vibratory sieve dispenser | **Low-Med** — mechanically feasible, but electronics, balance integration, and control tuning make schedule risk highest | **~0.1–1 mg**, limited in practice by balance resolution, latency, and release quantization; best path toward robust low-mg / sub-mg dosing | **~1–5%** once tuned; worse if release comes in large clumps | Control overshoot due to delayed weighing, clogging then burst release, vibration coupling into balance, added software/electronics risk | Closest to commercial gravimetric dispensers such as Quantos in workflow intent; vibratory sieve systems demonstrate mg-scale control, and comparative automation studies suggest closed-loop gravimetric platforms outperform clog-prone volumetric dispensers on difficult powders (besenhard2015accuracyofmicro pages 2-4, jiang2023autonomousbiomimeticsolid pages 10-10) |

*Table: This table compares the eight alternative powder-dispensing concepts for one-day-build practicality, likely dose floor and precision on cohesive fine powders, failure modes, and the closest retrieved literature/vendor analogues. It is useful for quickly identifying which concepts are both novel relative to the scoop/trough prototypes and plausible on a Genmitsu 3018-Pro V2.*

## Q1. Strongest one-day candidates that are genuinely different from scoop and bimodal trough
**Recommended shortlist:** **G, A, B, C**.

- **G (ERM vibratory sieve)**: Different from scoop/trough because it is a **flow-through-orifice** metering device driven by vibration, not a discrete excavate-and-dump geometry. It aligns with peer-reviewed vibratory sieve/chute microdosing behavior, including clear excitation thresholds and spill regimes (besenhard2015accuracyofmicro pages 4-5).

- **A (gantry-tap sieve)**: Different because it uses **impact-triggered release** rather than volume capture/dump. It is the fastest to build and makes cohesion an ally: powder may stay “stuck” until a tap breaks arching—similar to the need for sufficient excitation in vibratory systems (besenhard2015accuracyofmicro pages 4-5).

- **B (chamber strip)**: Different because it is true **positive displacement volumetry** with many pre-metered shots. It borrows the “cavity metering” idea that underlies many low-dose filling systems, but without the sophisticated powder-bed conditioning that makes them work well on cohesive fines (faulhammer2014lowdosecapsulefilling pages 1-2, faulhammerUnknownyeareffectofprocess pages 2-4).

- **C (capillary + wiper)**: Different because it is **tip-based micro-volumetry** with a shear release step. It is most analogous in spirit to PowderPicking (alsenz2011powderpickinganinexpensive pages 1-2), and would be a distinct primitive compared with your scoop/trough.

## Q2. Realistic minimum dose, expected RSD, dominant failure mode (cohesive sub‑100‑µm)
The ranges below are engineering estimates constrained by the literature anchors; they should be interpreted as **likely** performance bands for a one-day prototype.

### A. Tap-driven sieve cup
- **Min dose:** ~1–5 mg open-loop; ~0.5–2 mg with iterative gravimetric “tap until target” (bounded by release quantization).
- **Expected RSD:** ~10–30% open-loop; ~5–15% with closed-loop iteration.
- **Dominant failure:** no-flow if impulse < threshold (analogous to no-flow below vibration amplitude 30E in MG2 Microdose tests) (besenhard2015accuracyofmicro pages 4-5); or burst/spillage at excessive impulse (besenhard2015accuracyofmicro pages 4-5).

### B. Chamber strip
- **Min dose:** ~1–10 mg typical for printed cavities with practical strike-off.
- **Expected RSD:** ~10–25% for cohesive fines unless you add a compaction/conditioning step; best-case on better-flowing powders can be much lower.
- **Dominant failure:** partial/variable cavity fill (non-volumetric behavior) analogous to the “Group II” cohesive regime in dosator filling where behavior departs from volumetric and variability rises (faulhammer2014lowdosecapsulefilling pages 1-2, faulhammerUnknownyeareffectofprocess pages 2-4).

### C. Capillary dip + wiper
- **Min dose:** ~0.5–5 mg; potentially down toward 0.1–1 mg with tuning and/or iteration.
- **Expected RSD:** ~8–20% for cohesive powders; potentially better on specific powders.
- **Dominant failure:** clogging/plugging of the capillary and outside-of-tip contamination. Manual PowderPicking succeeds partly via repeated “picking” insertions, tapping to compact the source bed, and wiping external powder (alsenz2011powderpickinganinexpensive pages 1-2). Commercial automation can fail when compressible solids clog the dispenser (jiang2023autonomousbiomimeticsolid pages 10-10).

### D. Brush + comb
- **Min dose:** ~0.1–2 mg “transfer” is plausible; true microgram dosing is not realistic without closed-loop weigh.
- **Expected RSD:** ~20–100%+ (highly material/humidity dependent).
- **Dominant failure:** uncontrolled electrostatic adhesion and carryover; progressive loading memory (carryover between dispenses).

### E. Salt-shaker XY oscillation
- **Min dose:** ~1–10 mg.
- **Expected RSD:** ~15–40% open-loop.
- **Dominant failure:** same as A plus lateral slosh/spillage sensitivity; vibratory sieve systems show spillage at high excitation and no-flow at low excitation (besenhard2015accuracyofmicro pages 4-5).

### F. Passive auger (rack-and-pinion)
- **Min dose:** ~2–20 mg per stroke (without active anti-bridging features).
- **Expected RSD:** ~10–30% (density drift and bridging dominate).
- **Dominant failure:** inlet bridging/ratholing (common in gravity-fed devices) (hou2024developmentofa pages 44-47) and cohesive chunking leading to intermittent overdoses (besenhard2017microfeedinganddosing pages 1-6).

### G. Tap-driven sieve + ERM motor
- **Min dose:** ~0.5–2 mg open-loop after tuning; ~0.2–1 mg with iterative gravimetric stop.
- **Expected RSD:** ~5–15% open-loop; ~3–10% with closed-loop stopping.
- **Dominant failure:** mesh blinding and bed-history sensitivity; too-low excitation yields no flow (vibratory threshold behavior) and too-high yields spillage (besenhard2015accuracyofmicro pages 4-5).

### H. Solenoid-tapped sieve, closed-loop with external 0.1 mg balance
- **Min dose:** ~0.1–1 mg is plausible once tuned; below that you are limited by control latency and the discrete “lumpiness” of release events.
- **Expected RSD:** ~1–5% after tuning.
- **Dominant failure:** control overshoot/undershoot due to balance latency and occasional clog-then-burst events (consistent with the need for closed-loop amplitude modulation to prevent overshoot in vibratory sieve systems) (besenhard2015accuracyofmicro pages 2-4).

## Q3. Published/vendor-documented analogues (and when none were found)
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

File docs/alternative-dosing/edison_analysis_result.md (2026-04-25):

# Edison analysis task `9f148613-a5e8-4259-8048-f4cebc0f9c61`

status: `fail`

No formatted answer was returned.

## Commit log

2026-04-24 Update copilot instructions for CAD drawings
    Added instruction to recompile/render CAD drawings after changes.
2026-04-24 Preliminary design for top-ranked sieve-cup concepts (A and G)
    Agent-Logs-Url: https://github.com/vertical-cloud-lab/powder-excavator/sessions/630f9e78-f9e6-4419-b871-d8120f5b8fa2
    [sieve-cup-erm.stl, sieve-cup.stl, sieve_cup.scad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]
2026-04-24 Refine each A-H alternative individually with SCAD/STL/cutaway/spin/slice + composites + Edison analysis submit
    Agent-Logs-Url: https://github.com/vertical-cloud-lab/powder-excavator/sessions/019a026e-9754-4694-8337-068f1b297d52
    [A-tap-sieve.stl, A_tap_sieve.scad, B-pez-strip.stl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]
2026-04-25 Add per-concept annotated explainer panels + composite (title + iso + cutaway + numbered parts + 3-step cycle); resubmit Edison analysis with 42 attachments
    Agent-Logs-Url: https://github.com/vertical-cloud-lab/powder-excavator/sessions/01747380-9275-403f-a74d-c645515263a7
2026-04-25 Add 2-D dispensing animations (per-concept + composite); resubmit Edison analysis with animations attached
    Agent-Logs-Url: https://github.com/vertical-cloud-lab/powder-excavator/sessions/60d8488b-6dc5-446c-9458-c915cc891ff0

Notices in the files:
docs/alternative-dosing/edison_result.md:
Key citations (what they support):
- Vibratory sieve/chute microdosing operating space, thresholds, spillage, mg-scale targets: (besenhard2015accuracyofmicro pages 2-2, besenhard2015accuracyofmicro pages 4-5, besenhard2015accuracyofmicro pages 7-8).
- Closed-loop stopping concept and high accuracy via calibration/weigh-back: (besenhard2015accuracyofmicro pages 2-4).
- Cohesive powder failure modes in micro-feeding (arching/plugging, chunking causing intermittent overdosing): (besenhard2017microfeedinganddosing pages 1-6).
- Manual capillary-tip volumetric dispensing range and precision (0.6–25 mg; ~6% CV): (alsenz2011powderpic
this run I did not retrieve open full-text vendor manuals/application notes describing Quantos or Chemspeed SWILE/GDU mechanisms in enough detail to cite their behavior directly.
